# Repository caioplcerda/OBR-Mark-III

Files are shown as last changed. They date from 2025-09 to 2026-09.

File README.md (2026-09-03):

# OBR Mark III — Autonomous Rescue Robot

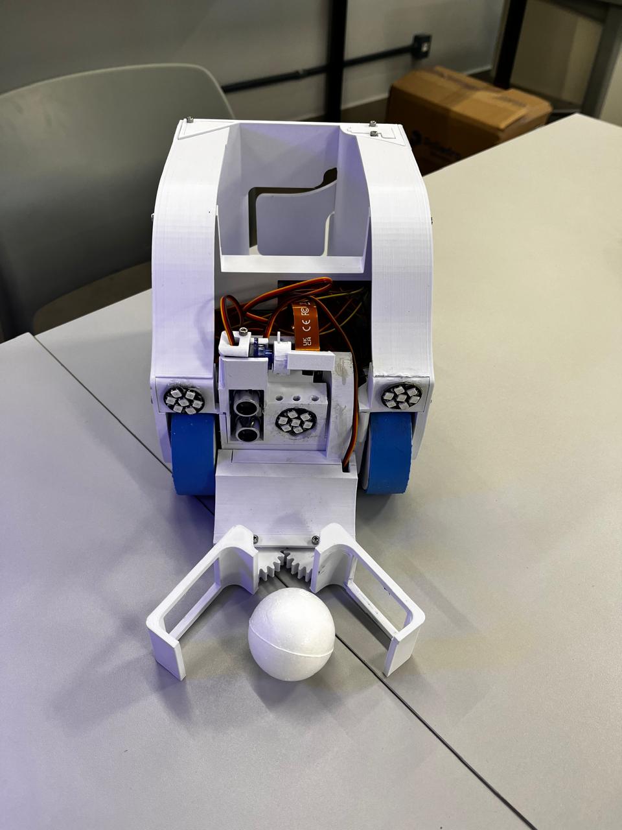
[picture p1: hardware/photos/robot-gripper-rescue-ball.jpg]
OBR Mark III closing its gripper on a rescue ball


An autonomous robot built for the **Olimpíada Brasileira de Robótica (OBR) 2025**, Brazil's
national robotics olympiad. It reads green intersection markers, avoids obstacles, collects
rescue balls with a rack-and-pinion gripper, and is tuned live from a browser while it drives.

**It follows the line with computer vision — no infrared sensor array.** Most line-following
robots read the track with a row of IR reflectance sensors a few millimetres above the
ground. This one has a camera and a **Raspberry Pi 5 (4 GB)**, and the line exists only as
pixels. Every steering decision comes out of a real-time OpenCV pipeline running at 480p.

Every structural part was designed in Fusion 360 and 3D printed in PLA. The tyres are custom
silicone, cast in a printed two-part mould, because printed wheels would not hold the track.

---

## What it does

### Finding the line in pixels

The pipeline never thresholds the whole frame looking for a blob. It samples it:

1. **Zero scan.** A horizontal scanline is taken close to the robot and the intensity
   profile along it is differentiated. The line's edges appear as derivative peaks, which
   is robust to uneven lighting in a way that a fixed brightness threshold is not. A
   minimum width of 12 px rejects noise and shadow edges.
2. **Circular scans.** From that first point, the algorithm sweeps arcs of radius 22 px
   through 180° to find where the line continues, then repeats from the new point —
   walking the track forward, several steps ahead of the robot. The traced path is kept in
   a rolling 7-point history.
3. **Steering.** A PID controller acts on the lateral offset of the nearest point, with the
   angle of the traced path fed forward. Because the path is known several points ahead,
   the robot slows into corners rather than discovering them late.

The scan-and-derivative approach is ported from a RoboCup Junior 2014 C++ reference
implementation (`rcj2014_port.py`) and re-derived in Python.

**Optical encoder feedback.** Each wheel reports its own speed, so the controller corrects
for the two motors never being quite identical — the usual reason a differential-drive robot
drifts on a straight line.

**Green intersection markers.** OBR arenas mark junctions with green patches indicating which
branch to take. The vision pipeline segments them in HSV, decides the turn, and executes a
180° reversal when two markers appear at once.

**Rescue-ball retrieval.** A rack-and-pinion gripper driven by an MG996R closes on the ball
and lifts it into an onboard reservoir.

**Camera mounted upside down.** The physical layout forced a 180° camera rotation; the
software rotates every frame before processing rather than fighting it mechanically.

**Thick-line support.** Morphological operations and contour analysis handle track lines up
to 20 mm wide, which break naive centroid-following.

**Live tuning over the network.** A Flask + Socket.IO server streams the robot's own camera
view to a browser and exposes PID gains, HSV thresholds and speed limits as live controls.
Tuning happens while the robot drives, with no reflashing and no reboot.

---

## The parts that were actually hard

### The Raspberry Pi 5 broke every GPIO library

The Pi 5 moved its GPIO behind the RP1 southbridge, and `RPi.GPIO` — the library every
Raspberry Pi robotics tutorial is written against — does not work on it. Nothing we started
from ran.

`hardware_control.py` therefore carries its own **GPIO backend abstraction**: a
`_GPIOBackendBase` interface with pin setup, PWM, and edge-triggered interrupts, implemented
over `lgpio`. Motor control, encoder interrupts and servo PWM all go through it, so the
control code is written once against an interface rather than against whichever library
happens to work on that board revision.

### The LEDs and the motors fought over the same timer

WS2812 addressable LEDs are timing-critical — each bit is a pulse width measured in hundreds
of nanoseconds, and they are usually driven from the Pi's PWM/DMA hardware. The motors need
PWM too. Driving the motors with *software* PWM produced jitter that corrupted the LED
signal; driving the LEDs while software PWM ran produced motor stutter.

The fix is one line of intent in the source — the backend forces **hardware PWM through
lgpio** specifically so the motor channels do not contend with the WS2812 timing. Finding
that took considerably longer than fixing it.

### Cascaded control, not a single PID

There are **three** PID controllers running at 50 Hz:

| Loop | Gains | Job |
|---|---|---|
| Directional (outer) | kp 0.9, kd 0.14 | Turns line error into a steering command |
| Left wheel velocity (inner) | kp 0.25, ki 0.35 | Holds the commanded wheel speed |
| Right wheel velocity (inner) | kp 0.25, ki 0.35 | Same, independently |

The outer loop asks for a turn rate; the inner loops make each wheel actually deliver its
share of it, from optical encoder feedback at 36 ticks per revolution. Without the inner
loops the robot steers correctly and still drifts, because no two DC motors respond
identically to the same duty cycle — the outer loop cannot tell the difference between "the
line moved" and "the left motor is lazy today."

If the encoders fail, the controller detects it and degrades to open loop rather than
stopping.

### Telling a junction apart from a sharp corner

The hardest perception problem in OBR is not finding the line. It is deciding whether the
line suddenly getting wider means *a junction is coming* or *the track turns 90° here* —
because the correct responses are opposite, and getting it wrong ends the run.

`_detect_intersection()` separates them geometrically. It samples the line's width across
the bottom strips and the lateral shift between the bottom and top centroids, then combines
them with the fitted path angle: wide and straight reads as an intersection; a large
centroid shift with a steep angle reads as a 90° curve.

### Nothing is trusted on one frame

Every detector — intersections, 90° curves, green markers — is **debounced over consecutive
frames** before the robot acts on it. A single frame of glare on the track, or one shadow
across a green patch, would otherwise send the robot down the wrong branch at full speed.

Thresholding is adaptive (`ADAPTIVE_THRESH_MEAN_C`, 21 px window) rather than fixed, because
competition lighting varies across the arena and a global threshold that works at one end of
the table fails at the other.

---

## The robot

| | |
|---|---|
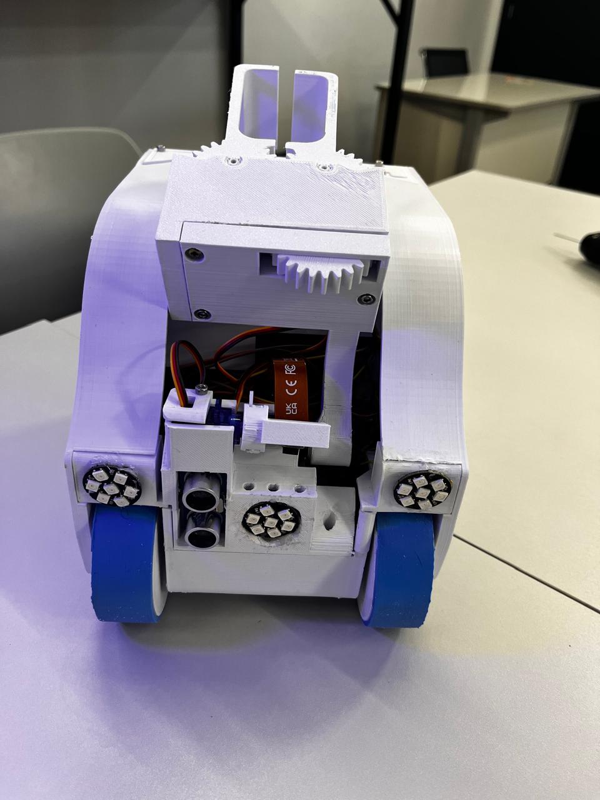
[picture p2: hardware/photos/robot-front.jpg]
Front
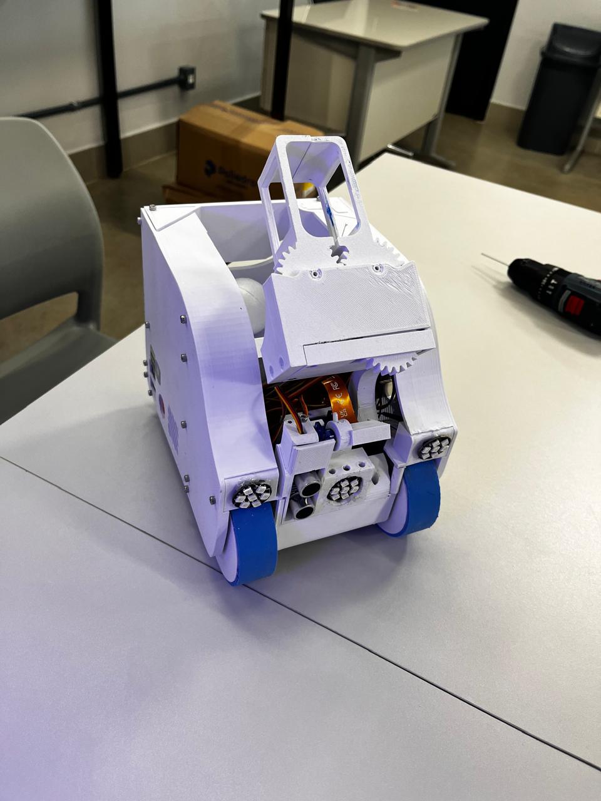
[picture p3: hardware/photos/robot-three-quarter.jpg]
Three-quarter
|  |  |
| Front — WS2812 indicator rings, ultrasonic sensor, silicone tyres | Reservoir loaded, gripper raised |

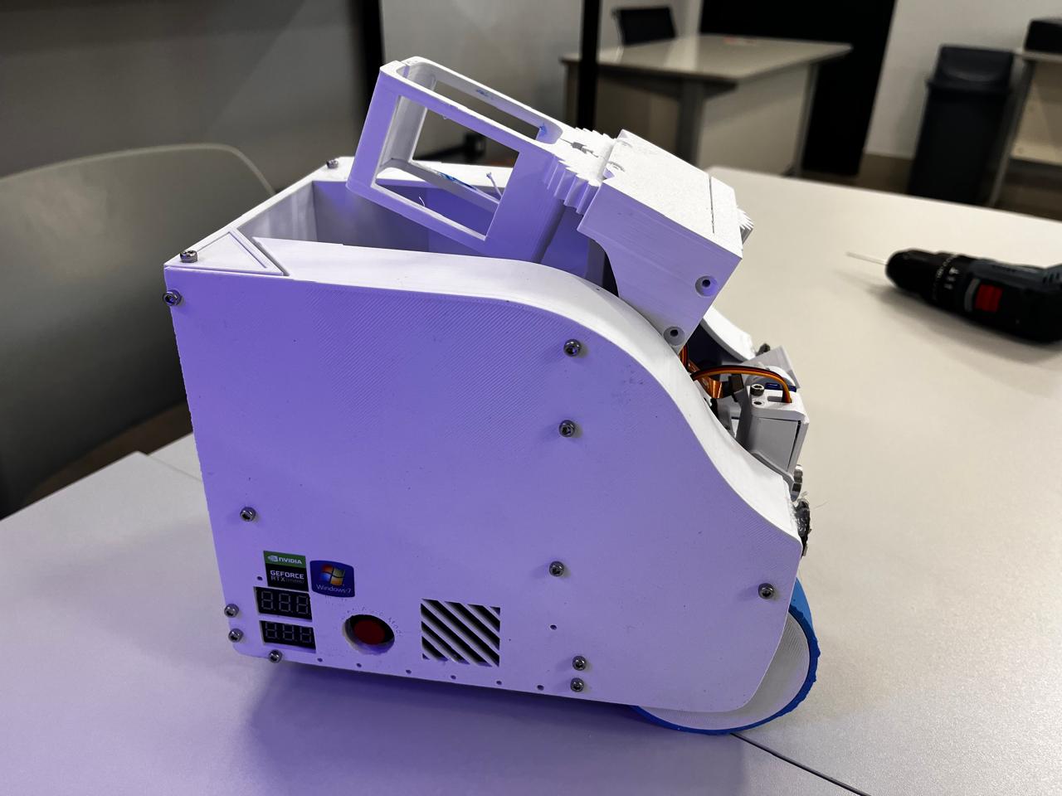
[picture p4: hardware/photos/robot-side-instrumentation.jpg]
Side view with voltmeters and power switch


Four panel voltmeters report pack and rail voltages at a glance, next to the main power
switch and a printed ventilation grille — useful when you are debugging in a pit between
rounds and need to know the battery state without a laptop.

---

## Architecture

```
src/
├── main.py               State machine — orchestrates behaviour and mode transitions
├── vision.py             Camera pipeline: rotation, thresholding, line and marker detection
├── line_follower.py      PID control, adaptive look-ahead, error computation
├── hardware_control.py   Motor, encoder and servo abstraction over the TB6612FNG drivers
├── web_stream.py         Flask + Socket.IO live video and remote calibration
├── led_control.py        WS2812 status indicators
├── rcj2014_port.py       Scan and error logic ported from the RoboCup Junior 2014 C++ reference
└── index.html            Calibration interface
```

Roughly 1,200 lines of Python across the core modules.

---

## Bill of materials

### Compute and sensing
| Part | Qty |
|---|---|
| Raspberry Pi 5, 4 GB — runs the whole vision pipeline on-board | 1 |
| Picamera3 Wide (mounted inverted) | 1 |
| Ultrasonic distance sensor | 1 |
| Optical encoder speed-sensor modules | 2 |

### Drive
| Part | Qty |
|---|---|
| DC motor, metal reduction gearbox, reversible | 2 |
| TB6612FNG dual H-bridge driver | 2 |
| Hex hub, 12 mm, for 8 mm shaft | 2 |
| Metal caster ball | 1 |
| Silicone tyres, cast in a printed mould | 2 |

### Actuators
| Part | Qty |
|---|---|
| TowerPro MG996R metal-gear servo (gripper) | 1 |
| SG90 9 g micro servo | 3 |
| Circular servo flange | 3 |

### Power
| Part | Qty |
|---|---|
| 18650 Li-Ion cell, 3.7 V (2550 mAh / Samsung 30Q 3000 mAh) | 8 |
| 4-cell 18650 holder, SMT PCB | 2 |
| BMS protection board, 5S 25 A 21 V | 1 |
| BMS protection board, 3S | 1 |
| MP1584 mini DC-DC step-down, 3 A | 5 |
| Mini-560 DC-DC step-down, 5 V | 1 |
| Adjustable current/voltage regulator | 2 |
| 3-digit digital voltmeter | 4 |
| 6A8 rectifier diode, 6 A 800 V | 2 |
| 1000 µF 16 V electrolytic capacitor | 1 |
| 100 pF 50 V ceramic capacitor | 10 |
| R13-507 16 mm momentary switch, 6 A | 1 |
| Dual 18650 charger | 1 |

### Indication and thermal
| Part | Qty |
|---|---|
| WS2812 addressable RGB module, 4-bit | 2 |
| WS2812 addressable RGB module, 7-bit | 1 |
| 40 × 40 × 10 mm fan | 2 |
| Self-adhesive heatsink | 5 |

### Mechanical
| Part | Qty |
|---|---|
| PLA filament — full chassis, gripper, mounts, wheel mould | — |
| M3 × 25 mm Philips screw | 50 |
| M3 nut | 30 |
| M2.5 × 6 mm Philips screw | 50 |
| M3 × 5 × 4.2 heat-set threaded insert | 1 kit |
| 6-way locking connector | 2 |

Threaded brass inserts were heat-set into the printed parts rather than tapping screws
directly into PLA, so the assembly survives repeated disassembly between competition rounds.

---

## CAD

**[`hardware/cad/obr-mark-iii.stl`](hardware/cad/obr-mark-iii.stl) — click to open it in
GitHub's interactive 3D viewer.** Rotate and zoom the assembly in the browser; nothing to
install.

Also committed: `obr-mark-iii.3mf`, print-ready with units and metadata preserved.
67,842 triangles.

### On the tyres

Printed PLA wheels slip on the OBR track surface, especially on inclines. Rather than buy
rubber wheels that would not fit the chassis geometry, we modelled a two-part mould, printed
it, and cast the tyres in silicone. The result grips the track and can be recast in minutes
if one tears mid-competition.

---

## Running it

The modules import each other flatly, and `web_stream.py` serves `index.html` from its own
directory, so run from inside `src/`:

```bash
pip install -r requirements.txt
cd src
python main.py
```

The calibration interface is then at `http://<robot-ip>:5000`.

Hardware-dependent imports (`RPi.GPIO`, `picamera2`, `libcamera`) are guarded, so the vision
and control modules can be exercised on a development machine without the robot attached.

---

## Tests

```bash
pip install -r requirements-dev.txt
pytest -q
```

31 tests over the two modules that decide where the robot goes: the scanline and
derivative line detection in `rcj2014_port.py`, and green-marker detection in `vision.py`.

The cases that matter are the negative ones. A dark speck narrower than the minimum line width
is noise, not the line. A green marker in the top half of the frame is track the robot has not
reached yet. A marker inside the outer 10% of the frame belongs to an adjacent lane. Each of
those filters exists because acting on the wrong one sends the robot down the wrong branch.

Writing them turned up a real bug: `calibrate_by_click` sliced the frame as
`frame_bgr[y, x:x+1]`, which produces a `(1, 3)` array. `cv2.cvtColor` needs `(1, 1, 3)` and
raised every time, and because the exception was caught and logged, click-to-calibrate had
never worked — it just looked like error handling.

## Repository layout

| Path | |
|---|---|
| `src/` | Robot code — the modules above |
| `tests/` | 31 tests over line detection and green-marker detection |
| `hardware/cad/` | Fusion 360 exports: STL and 3MF |
| `hardware/photos/` | Robot photographs |
| `experiments/` | Bring-up scripts kept from development: servo sweeps, LED and SPI tests, encoder checks, earlier vision attempts |
| `docs/` | Wiring and tuning notes |

`experiments/` is deliberately preserved. Getting three servos, an SPI LED strip and two
encoders working reliably took a lot of small scripts, and that iteration is part of the
project.

---

## Built by

Caio Lacerda — [github.com/caioplcerda](https://github.com/caioplcerda) ·
[linkedin.com/in/caio-lacerda](https://linkedin.com/in/caio-lacerda-61b7081b9)

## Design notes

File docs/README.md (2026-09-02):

# Notes

Wiring diagrams, pin assignments and PID tuning notes go here.

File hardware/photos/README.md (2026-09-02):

# Photos

| File | |
|---|---|
| `robot-gripper-rescue-ball.jpg` | Gripper closing on a rescue ball — README hero |
| `robot-front.jpg` | Front: WS2812 rings, ultrasonic sensor, silicone tyres |
| `robot-three-quarter.jpg` | Reservoir loaded, gripper raised |
| `robot-side-instrumentation.jpg` | Panel voltmeters, power switch, ventilation grille |

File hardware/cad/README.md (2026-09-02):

# CAD — OBR Mark III

Designed in Fusion 360, printed in PLA.

| File | | |
|---|---|---|
| `obr-mark-iii.stl` | 3.2 MB · 67,842 triangles | **GitHub renders this in an interactive 3D viewer — click it** |
| `obr-mark-iii.3mf` | 910 KB | Print-ready, keeps units and metadata |

Model bounding box: 272 × 363 × 190 mm.

The Fusion native `.f3d` (75 MB) is deliberately not committed — it is too large to be
useful in a git history and unreadable without Fusion. Ask if you want the source file,
or use the public share link in the main README.

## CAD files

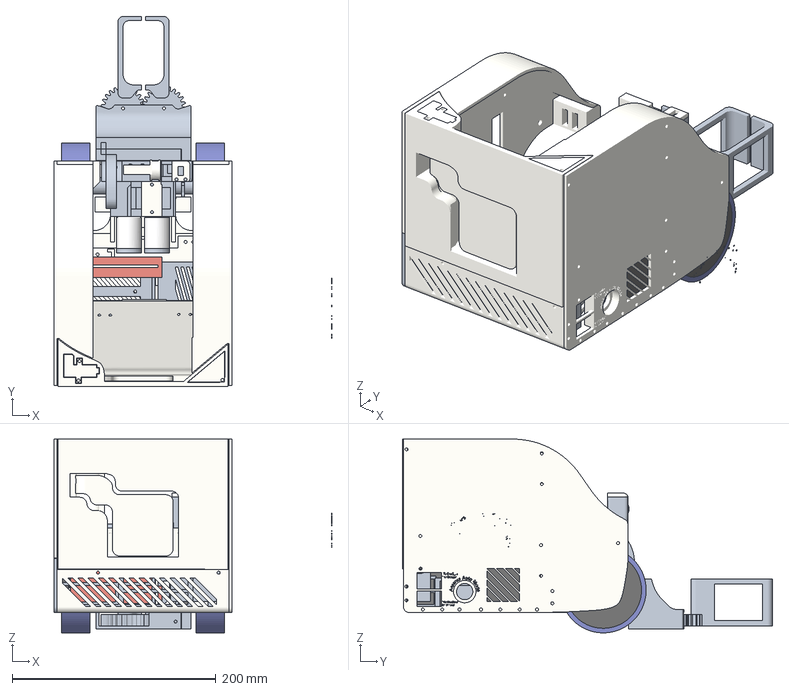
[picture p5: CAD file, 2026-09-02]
hardware/cad/obr-mark-iii.3mf
272.3 x 362.8 x 190.0 mm
ImageToStl.com_Captura+de+tela+2025-08-05+210000 (1)
ImageToStl.com_Captura+de+tela+2025-08-05+210000 (10)
ImageToStl.com_Captura+de+tela+2025-08-05+210000 (11)
ImageToStl.com_Captura+de+tela+2025-08-05+210000 (12)
ImageToStl.com_Captura+de+tela+2025-08-05+210000 (13)
ImageToStl.com_Captura+de+tela+2025-08-05+210000 (14)
ImageToStl.com_Captura+de+tela+2025-08-05+210000 (15)
ImageToStl.com_Captura+de+tela+2025-08-05+210000 (16)
ImageToStl.com_Captura+de+tela+2025-08-05+210000 (17)
ImageToStl.com_Captura+de+tela+2025-08-05+210000 (18)
ImageToStl.com_Captura+de+tela+2025-08-05+210000 (19)
ImageToStl.com_Captura+de+tela+2025-08-05+210000 (2)
ImageToStl.com_Captura+de+tela+2025-08-05+210000 (20)
ImageToStl.com_Captura+de+tela+2025-08-05+210000 (21)
ImageToStl.com_Captura+de+tela+2025-08-05+210000 (22)
ImageToStl.com_Captura+de+tela+2025-08-05+210000 (23)
ImageToStl.com_Captura+de+tela+2025-08-05+210000 (24)
ImageToStl.com_Captura+de+tela+2025-08-05+210000 (25)
ImageToStl.com_Captura+de+tela+2025-08-05+210000 (26)
ImageToStl.com_Captura+de+tela+2025-08-05+210000 (27)
ImageToStl.com_Captura+de+tela+2025-08-05+210000 (28)
ImageToStl.com_Captura+de+tela+2025-08-05+210000 (29)
ImageToStl.com_Captura+de+tela+2025-08-05+210000 (3)
ImageToStl.com_Captura+de+tela+2025-08-05+210000 (30)
ImageToStl.com_Captura+de+tela+2025-08-05+210000 (31)
ImageToStl.com_Captura+de+tela+2025-08-05+210000 (4)
ImageToStl.com_Captura+de+tela+2025-08-05+210000 (5)
ImageToStl.com_Captura+de+tela+2025-08-05+210000 (6)
ImageToStl.com_Captura+de+tela+2025-08-05+210000 (7)
ImageToStl.com_Captura+de+tela+2025-08-05+210000 (8)
ImageToStl.com_Captura+de+tela+2025-08-05+210000 (9)
Parede Esquerda (1)
Parede direita
Peneu AZUL (1)
Peneu AZUL
Porta bateria
Roda AZUL (1)
Roda AZUL
Segundo andar
Tampa
acoplador (1)
acoplador
base garra
camera
chassi (3) (1)
chassi (3)
chave bat
disco de encoder
engrenagem servo garra (1) (1)
engrenagem servo garra (1)
fecha garra
m
motor (1) (1)
motor (1)
rasp
rolamento (2) (1)
rolamento (2)
tampa caixa (1) (2)
tampa caixa
tampa motor (2)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

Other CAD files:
hardware/cad/obr-mark-iii.stl

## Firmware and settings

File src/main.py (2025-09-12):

# main.py corrigido
# Segue-linha robusto + UI web + botão físico.
# Ajustes:
#  - Logs claros para detecção de verde
#  - Tempos de curva fáceis de calibrar
#  - Giro menos brusco (bias reduzido)

import os
import cv2
import time
import json
import threading
import numpy as np
import math
from datetime import datetime
from collections import deque

USE_LEDS = True

WEB_AVAILABLE = True
SHARED_STATE = {
    "config": {},
    "last_frame": None,
    "speeds": {"left": 0, "right": 0},
    "view_mode": "preview",
    "status": "idle",
    "fps": 0.0,
    "log": [],
}
try:
    import web_stream
    if hasattr(web_stream, "SHARED_STATE"):
        SHARED_STATE = web_stream.SHARED_STATE
    WEB_AVAILABLE = True
except Exception:
    WEB_AVAILABLE = False

GPIO_AVAILABLE = True
try:
    import RPi.GPIO as GPIO
    GPIO.setwarnings(False)
    GPIO.setmode(GPIO.BCM)
    try:
        GPIO.setup(21, GPIO.IN, pull_up_down=GPIO.PUD_UP)
        GPIO.cleanup(21)
    except Exception:
        GPIO_AVAILABLE = False
except Exception:
    GPIO_AVAILABLE = False

from hardware_control import HardwareControl
from vision import Vision
try:
    from led_control import LedController
except Exception:
    LedController = None

PICAMERA_AVAILABLE = True
try:
    from picamera2 import Picamera2
    try:
        from libcamera import Transform
    except Exception:
        Transform = None
    PICAMERA_AVAILABLE = True
except Exception:
    PICAMERA_AVAILABLE = False

def log(msg: str):
    stamp = datetime.now().strftime("%H:%M:%S")
    line = f"[{stamp}] {msg}"
    print(line, flush=True)
    try:
        SHARED_STATE["log"].append(line)
        if len(SHARED_STATE["log"]) > 300:
            SHARED_STATE["log"] = SHARED_STATE["log"][-300:]
    except Exception:
        pass

class Camera:
    def __init__(self, width=640, height=480, rotate_180=False):
        self.width = width
        self.height = height
        self.rotate_180 = rotate_180
        self.picam = None
        self.cap = None
        try:
            import cv2 as _cv2
            _cv2.setNumThreads(1)
        except Exception:
            pass

        if PICAMERA_AVAILABLE:
            try:
                self.picam = Picamera2()
                if Transform is not None:
                    cfg = self.picam.create_video_configuration(
                        main={"size": (self.width, self.height), "format": "RGB888"},
                        transform=Transform(hflip=0, vflip=0),
                        buffer_count=3
                    )
                else:
                    cfg = self.picam.create_video_configuration(
                        main={"size": (self.width, self.height), "format": "RGB888"},
                        buffer_count=3
                    )
                self.picam.configure(cfg)
                try:
                    self.picam.set_controls({"FrameDurationLimits": (10000, 33333)})
                except Exception:
                    pass
                self.picam.start()
                log("Picamera2 iniciada em modo vídeo.")
            except Exception as e:
                log(f"Falha Picamera2: {e}. Usando OpenCV/USB.")
                self.picam = None

        if self.picam is None:
            self.cap = cv2.VideoCapture(0)
            self.cap.set(cv2.CAP_PROP_FRAME_WIDTH, self.width)
            self.cap.set(cv2.CAP_PROP_FRAME_HEIGHT, self.height)
            self.cap.set(cv2.CAP_PROP_FPS, 30)
            if not self.cap.isOpened():
                raise RuntimeError("Nenhuma câmera disponível.")

    def read(self):
        if self.picam is not None:
            rgb = self.picam.capture_array()
            frame_bgr = cv2.cvtColor(rgb, cv2.COLOR_RGB2BGR)
        else:
            ok, frame_bgr = self.cap.read()
            if not ok:
                raise RuntimeError("Falha ao ler frame da câmera USB.")
        if self.rotate_180:
            frame_bgr = cv2.rotate(frame_bgr, cv2.ROTATE_180)
        return frame_bgr

    def release(self):
        try:
            if self.picam is not None:
                self.picam.stop()
            if self.cap is not None:
                self.cap.release()
        except Exception:
            pass

class Robot:
    WIDTH = 640
    HEIGHT = 480

    BASE_SPEED = 50
    MIX_ANGLE = 0.7
    MAX_ANGLE = 50.0

    N_STRIPS = 5
    STRIP_H = 28
    STRIP_BOTTOM = 440

    INTERSECT_DEBOUNCE = 6
    C90_DEBOUNCE = 5
    GREEN_DEBOUNCE = 4

    # tempos calibráveis
    INTERSECT_FWD_TIME = 0.8
    TURN90_FWD_TIME = 0.3
    TURN90_TURN_TIME = 0.8 

    PID_DEFAULTS = {"kp": 0.5, "ki": 0.0, "kd": 0.12, "sample_time": 0.025}

    def __init__(self):
        self.running = False
        self.thread = None

        self.camera = Camera(self.WIDTH, self.HEIGHT, rotate_180=False)
        self.vision = Vision({}, log)
        self.hardware = HardwareControl({"pid": dict(self.PID_DEFAULTS)})

        self.history = deque(maxlen=5)
        self._intersect_seen = 0
        self._c90_seen = 0
        self._green_seen = 0
        self._green_last = None

    def start(self):
        if self.running:
            log("Robô já está rodando.")
            return
        self.running = True
        self.thread = threading.Thread(target=self._loop, daemon=True)
        self.thread.start()
        SHARED_STATE["status"] = "running"
        log("Loop principal iniciado.")

    def stop(self):
        self.running = False
        SHARED_STATE["status"] = "stopped"
        try: self.hardware.stop()
        except Exception: pass
        log("Parado.")

    def _drive(self, base_speed: float, error: float):
        try:
            self.hardware.set_motor_speed(base_speed, error)
        except Exception:
            pass

    def _forward_time(self, duration_s: float):
        self.hardware.set_motor_speed(self.BASE_SPEED, 0)
        start_time = time.time()
        while self.running and time.time() - start_time < duration_s:
            time.sleep(0.01)
        self.hardware.stop()

    def _turn_in_place_time(self, direction: str, duration_s: float):
        bias = 100 if direction == "left" else -100  # menos agressivo
        start_time = time.time()
        while self.running and time.time() - start_time < duration_s:
            self.hardware.set_motor_speed(0, bias)
            time.sleep(0.01)
        self.hardware.stop()

    def _loop(self):
        try:
            while self.running:
                frame = self.camera.read()
                bw = self._binarize(frame)

                cents, widths = [], []
                for i in range(self.N_STRIPS):
                    y0 = self.STRIP_BOTTOM - i*self.STRIP_H
                    c, w = self._strip_centroid(bw, y0, self.STRIP_H)
                    cents.append(c)
                    widths.append(w)

                valids = [p for p in cents if p is not None]
                angle = self._fit_angle(valids)

                is_intersection, is_curve90, _ = self._detect_intersection(bw, widths, cents, angle)

                if is_curve90:
                    self._c90_seen += 1
                else:
                    self._c90_seen = 0
                confirmed_curve90 = self._c90_seen >= self.C90_DEBOUNCE

                if is_intersection:
                    self._intersect_seen += 1
                else:
                    self._intersect_seen = 0
                confirmed_intersection = self._intersect_seen >= self.INTERSECT_DEBOUNCE

                green_centroids, green_dir = self.vision.detect_greens(frame)
                if green_dir:
                    self._green_last = green_dir
                    self._green_seen += 1
                else:
                    self._green_seen = 0
                confirmed_green = self._green_last if self._green_seen >= self.GREEN_DEBOUNCE else None

                # logs
                if confirmed_green:
                    log(f"Marcador verde confirmado: {confirmed_green}")

                if confirmed_intersection and not confirmed_curve90:
                    if confirmed_green == "uturn":
                        self._forward_time(self.INTERSECT_FWD_TIME)
                        self._turn_in_place_time("left", self.TURN90_TURN_TIME * 2)
                        log("Execução: U-Turn à esquerda")
                        self._green_seen = 0; self._intersect_seen = 0; self._green_last = None
                        continue
                    elif confirmed_green in ("left", "right"):
                        self._forward_time(self.TURN90_FWD_TIME)
                        self._turn_in_place_time(confirmed_green, self.TURN90_TURN_TIME)
                        log(f"Execução: curva {confirmed_green}")
                        self._green_seen = 0; self._intersect_seen = 0; self._green_last = None
                        continue
                    else:
                        self._forward_time(self.INTERSECT_FWD_TIME)
                        log("Execução: interseção sem verde → reto")
                        self._intersect_seen = 0
                        continue

                if valids:
                    offset = valids[0][0] - (self.WIDTH // 2)
                    error = float(offset) + self.MIX_ANGLE * float(angle)
                    self._drive(self.BASE_SPEED, error)
                else:
                    self.hardware.stop()

                SHARED_STATE["last_frame"] = frame
                SHARED_STATE["speeds"] = {
                    "left": self.hardware.last_left_speed,
                    "right": self.hardware.last_right_speed
                }
                time.sleep(0.01)
        except Exception as e:
            log(f"Erro no loop principal: {e}")
        finally:
            try: self.hardware.stop()
            except Exception: pass

    # ==== visão utilitários ====
    def _binarize(self, frame_bgr):
        gray = cv2.cvtColor(frame_bgr, cv2.COLOR_BGR2GRAY)
        bw = cv2.adaptiveThreshold(gray, 255, cv2.ADAPTIVE_THRESH_MEAN_C,
                                   cv2.THRESH_BINARY_INV, 21, 7)
        return bw

    def _strip_centroid(self, bw, y0, h):
        H, W = bw.shape[:2]
        y0 = max(0, min(H - 1, int(y0)))
        y1 = max(0, min(H, int(y0 + h)))
        roi = bw[y0:y1, :]
        colsum = roi.sum(axis=0)
        if colsum.max() < 255 * h * 0.05:
            return None, 0
        x = np.arange(0, W, dtype=np.float32)
        cx = float((x * colsum).sum() / (colsum.sum() + 1e-6))
        cy = int((y0 + y1) / 2)
        return (int(cx), int(cy)), int(np.count_nonzero(colsum))

    def _fit_angle(self, pts):
        if len(pts) < 2:
            return 0.0
        xs = np.array([p[0] for p in pts], dtype=np.float32)
        ys = np.array([p[1] for p in pts], dtype=np.float32)
        A = np.vstack([ys, np.ones_like(ys)]).T
        alpha, _ = np.linalg.lstsq(A, xs, rcond=None)[0]
        angle_deg = np.degrees(np.arctan2(alpha, 1.0))
        return float(np.clip(angle_deg, -self.MAX_ANGLE, self.MAX_ANGLE))

    def _detect_intersection(self, bw, widths, cents, angle_deg):
        bottom_widths = [w for w in widths[:3] if w > 0]
        is_wide = len(bottom_widths) > 0 and np.mean(bottom_widths) > 300
        is_intersection = is_wide and abs(angle_deg) < 15

        num_valid_cents = sum(1 for c in cents if c is not None)
        is_curve90 = False
        if num_valid_cents >= 3:
            bottom_cx = cents[0][0] if cents[0] is not None else self.WIDTH // 2
            top_cx = cents[-1][0] if cents[-1] is not None else self.WIDTH // 2
            shift_px = abs(bottom_cx - top_cx)
            is_curve90 = (shift_px > 80) and (abs(angle_deg) > 20)
        elif num_valid_cents >= 2:
            is_curve90 = abs(angle_deg) > 25

        return is_intersection, is_curve90, False

def _wire_web(robot: Robot):
    if not WEB_AVAILABLE:
        return
    try:
        if hasattr(web_stream, "register_robot"):
            web_stream.register_robot(robot)
            log("Robô registrado no servidor web.")
    except Exception as e:
        log(f"Falha ao integrar com web_stream: {e}")

def _setup_button(robot: Robot):
    if not GPIO_AVAILABLE:
        log("GPIO indisponível: sem botão físico.")
        return
    for pin in [21, 4]:
        try:
            GPIO.setup(pin, GPIO.IN, pull_up_down=GPIO.PUD_UP)
            def _toggle(channel):
                if GPIO.input(pin) == GPIO.LOW:
                    if robot.running:
                        robot.stop()
                    else:
                        robot.start()
            GPIO.add_event_detect(pin, GPIO.FALLING, callback=_toggle, bouncetime=300)
            log(f"Botão físico pronto no BCM {pin}.")
            break
        except Exception as e:
            log(f"Falha botão BCM {pin}: {e}")

def main():
    robot = Robot()
    _wire_web(robot)
    _setup_button(robot)

    if WEB_AVAILABLE and hasattr(web_stream, "app"):
        host = os.environ.get("HOST", "0.0.0.0")
        port = int(os.environ.get("PORT", "5000"))
        try:
            if hasattr(web_stream, "socketio"):
                web_stream.socketio.run(web_stream.app, host=host, port=port, allow_unsafe_werkzeug=True)
            else:
                web_stream.app.run(host=host, port=port)
        finally:
            robot.stop()
    else:
        try:
            while True:
                time.sleep(1.0)
        except KeyboardInterrupt:
            robot.stop()

if __name__ == "__main__":
    main()

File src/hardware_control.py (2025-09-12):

# hardware_control.py
# Controle de motores TB6612FNG (canal B), com opção de encoders (TPR=36).
# Usa backend lgpio (PWM por hardware) para não travar com WS2812.
# Direita invertida (chassi espelhado), deadband alto para vencer inércia,
# e "snap reto" quando erro é pequeno.

import time
import threading

# ------------------ Backends GPIO (forçando lgpio) ------------------
class _PWMBase:
    def start(self, duty): raise NotImplementedError
    def ChangeDutyCycle(self, duty): raise NotImplementedError
    def stop(self): raise NotImplementedError

class _GPIOBackendBase:
    OUT = 1
    IN = 0
    PUD_UP = 2
    RISING = 31
    def setup(self, pin, mode, pull_up_down=None): raise NotImplementedError
    def output(self, pin, level): raise NotImplementedError
    def input(self, pin): raise NotImplementedError
    def PWM(self, pin, freq_hz): raise NotImplementedError
    def add_event_detect(self, pin, edge, callback): raise NotImplementedError
    def remove_event_detect(self, pin): pass
    def cleanup(self): pass

class _LGPIOBackend(_GPIOBackendBase):
    def __init__(self, chip_index=0):
        import lgpio
        self._lgpio = lgpio
        self._h = self._lgpio.gpiochip_open(chip_index)
        self.OUT = 1; self.IN = 0; self.PUD_UP = 2
        self.RISING = self._lgpio.RISING_EDGE
        self._alerts = {}
    def _claim_out(self, pin, init=0):
        self._lgpio.gpio_claim_output(self._h, pin, init)
    def _claim_in(self, pin, pud=None):
        flags = 0
        if pud == self.PUD_UP:
            flags |= self._lgpio.SET_PULL_UP
        self._lgpio.gpio_claim_input(self._h, pin, flags)
    def setup(self, pin, mode, pull_up_down=None):
        if mode == self.OUT: self._claim_out(pin, 0)
        else: self._claim_in(pin, pull_up_down)
    def output(self, pin, level):
        self._lgpio.gpio_write(self._h, pin, 1 if level else 0)
    def input(self, pin):
        return self._lgpio.gpio_read(self._h, pin)
    class _PWM(_PWMBase):
        def __init__(self, lgpio_mod, handle, pin, freq):
            self._lgpio = lgpio_mod; self._h = handle; self._pin = pin; self._freq = int(freq)
            self._lgpio.gpio_claim_output(self._h, pin, 0)
        def start(self, duty):
            self.ChangeDutyCycle(duty)
        def ChangeDutyCycle(self, duty):
            self._lgpio.tx_pwm(self._h, self._pin, self._freq, max(0.0, min(100.0, float(duty))))
        def stop(self):
            try: self._lgpio.tx_pwm(self._h, self._pin, self._freq, 0)
            except Exception: pass
    def PWM(self, pin, freq_hz):
        return self._PWM(self._lgpio, self._h, pin, freq_hz)
    def add_event_detect(self, pin, edge, callback):
        self._lgpio.gpio_claim_input(self._h, pin, self._lgpio.SET_PULL_UP)
        self._lgpio.gpio_claim_alert(self._h, pin, self.RISING, 0)
        def _cb(_chip, _gpio, level, _tick):
            try:
                if level == 1:
                    callback(pin)
            except Exception:
                pass
        self._alerts[pin] = _cb
        self._lgpio.set_alert_func(self._h, pin, _cb)
    def remove_event_detect(self, pin):
        if pin in self._alerts:
            try: self._lgpio.set_alert_func(self._h, pin, None)
            except Exception: pass
            self._alerts.pop(pin, None)
    def cleanup(self):
        try:
            for pin in list(self._alerts.keys()):
                self.remove_event_detect(pin)
        except Exception:
            pass
        try:
            self._lgpio.gpiochip_close(self._h)
        except Exception:
            pass

def _make_backend_forced_lgpio():
    return _LGPIOBackend(), "lgpio"

# ------------------ PID simples ------------------
class PIDController:
    def __init__(self, kp=0.4, ki=0.0, kd=0.1, setpoint=0.0, sample_time=0.01, out_min=None, out_max=None):
        self.kp=float(kp); self.ki=float(ki); self.kd=float(kd)
        self.setpoint=float(setpoint); self.sample_time=float(sample_time)
        self._prev_error=0.0; self._integral=0.0; self._last_t=time.time()
        self.out_min=out_min; self.out_max=out_max
    def reset(self):
        self._prev_error=0.0; self._integral=0.0; self._last_t=time.time()
    def calculate(self, measurement):
        now=time.time(); dt=now-self._last_t
        if dt<self.sample_time: return self._prev_error
        error=self.setpoint-float(measurement)
        self._integral = max(-200.0, min(200.0, self._integral + error*dt))
        derivative=(error-self._prev_error)/dt if dt>0 else 0.0
        out=(self.kp*error)+(self.ki*self._integral)+(self.kd*derivative)
        if self.out_min is not None: out=max(self.out_min,out)
        if self.out_max is not None: out=min(self.out_max,out)
        self._prev_error=error; self._last_t=now
        return out
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

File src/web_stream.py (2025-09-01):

# web_stream.py
# Flask + Socket.IO + MJPEG robusto.
# Inclui "FORCE_RGB_INPUT" para evitar cores trocadas e stream preto.

import cv2
from flask import Flask, Response, send_from_directory, jsonify
from flask_socketio import SocketIO, emit
import threading
import time

app = Flask(__name__)
socketio = SocketIO(app, async_mode="threading", cors_allowed_origins="*")

# Se a imagem sair com cores invertidas, deixe True
FORCE_RGB_INPUT = False

# Estado compartilhado; o main.py pode sobrescrever esse dict
SHARED_STATE = {
    "config": {},
    "last_frame": None,          # numpy array (BGR ou RGB com flag)
    "speeds": {"left": 0, "right": 0},
    "status": "idle",
    "view_mode": "preview",
    "fps": 0.0,
    "log": [],
}

_robot = None
_state_lock = threading.Lock()

def register_robot(robot):
    global _robot
    _robot = robot

def _get_frame():
    with _state_lock:
        return SHARED_STATE.get("last_frame", None)

# MJPEG
def mjpeg_generator():
    while True:
        frame = _get_frame()
        if frame is None:
            time.sleep(0.05)
            continue
        try:
            img = frame
            if FORCE_RGB_INPUT:
                # se pipeline estiver em RGB, converte para BGR antes de encodar
                img = cv2.cvtColor(img, cv2.COLOR_RGB2BGR)
            ok, jpg = cv2.imencode(".jpg", img)
            if not ok:
                time.sleep(0.01)
                continue
            data = jpg.tobytes()
            yield (b"--frame\r\n"
                   b"Content-Type: image/jpeg\r\n\r\n" + data + b"\r\n")
        except Exception:
            time.sleep(0.01)

# Rotas
@app.route("/")
def root():
    return send_from_directory(".", "index.html")

@app.route("/index.html")
def serve_index():
    return send_from_directory(".", "index.html")

@app.route("/stream")
def stream():
    return Response(mjpeg_generator(),
                    mimetype="multipart/x-mixed-replace; boundary=frame")

@app.route("/state")
def state():
    with _state_lock:
        return jsonify({
            "status": SHARED_STATE.get("status", ""),
            "speeds": SHARED_STATE.get("speeds", {}),
            "fps": SHARED_STATE.get("fps", 0),
            "view_mode": SHARED_STATE.get("view_mode", "preview"),
        })

# Socket.IO
@socketio.on("connect")
def on_connect():
    emit("log_message", {"text": "Socket conectado."})
    with _state_lock:
        emit("status", {
            "status": SHARED_STATE.get("status", "idle"),
            "speeds": SHARED_STATE.get("speeds", {"left": 0, "right": 0}),
            "fps": SHARED_STATE.get("fps", 0)
        })

@socketio.on("command")
def on_command(cmd):
    global _robot
    name = (cmd or {}).get("name", "")
    data = (cmd or {}).get("data", {}) or {}

    if _robot is None:
        emit("log_message", {"text": "Nenhum robô registrado ainda."})
        return

    try:
        if name == "start_robot":
            _robot.start()
            emit("log_message", {"text": "Robô iniciado."})
        elif name == "stop_robot":
            _robot.stop()
            emit("log_message", {"text": "Robô parado."})
        elif name == "set_view_mode":
            _robot.set_view_mode(data.get("mode", "preview"))
        elif name == "calibrate_pixel":
            x = int(data.get("x", 0))
            y = int(data.get("y", 0))
            color = data.get("color", "black")
            ok = _robot.calibrate_pixel(x, y, color)
            emit("log_message", {"text": f"Calibração ({color}) {x},{y} -> {ok}"})
        elif name == "save_config":
            ok = _robot.save_config(data)
            emit("log_message", {"text": f"Config salva: {ok}"})
        else:
            emit("log_message", {"text": f"Comando desconhecido: {name}"})
    except Exception as e:
        emit("log_message", {"text": f"Erro no comando {name}: {e}"})


if __name__ == "__main__":
    socketio.run(app, host="0.0.0.0", port=5000, allow_unsafe_werkzeug=True)

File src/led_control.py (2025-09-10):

# led_control.py
# Simple controller for a single strip of WS2812 (NeoPixel) LEDs.

try:
    from rpi_ws281x import PixelStrip, Color, ws
    RPI_WS281X_OK = True
except Exception:
    RPI_WS281X_OK = False

TOTAL_LEDS = 21

class LedController:
    def __init__(self, pin=12, brightness=128):
        """
        pin: GPIO for the DIN of the WS2812 LEDs (GPIO12 recommended).
        brightness: 0..255 (global brightness for the strip).
        """
        self.enabled = False
        self.strip = None

        if not RPI_WS281X_OK:
            print("[LED] rpi_ws281x library not available — LEDs disabled.")
            return

        try:
            self.strip = PixelStrip(
                num=TOTAL_LEDS,
                pin=pin,
                freq_hz=800000,
                dma=10,
                invert=False,
                brightness=brightness,
                channel=0,
                strip_type=ws.WS2811_STRIP_GRB
            )
            self.strip.begin()
            self.enabled = True
            print(f"[LED] LedController initialized for {TOTAL_LEDS} LEDs.")
        except Exception as e:
            print(f"[LED] Failed to initialize PixelStrip: {e}")
            self.enabled = False

    @staticmethod
    def _rgb(r, g, b):
        """Converts RGB tuple to Color object."""
        return Color(int(r), int(g), int(b))

    def set_all(self, r, g, b, show=True):
        """
        Sets all LEDs in the strip to the same color.
        """
        if not self.enabled:
            return

        color_obj = self._rgb(r, g, b)
        for i in range(self.strip.numPixels()):
            self.strip.setPixelColor(i, color_obj)

        if show:
            self.strip.show()

    def cleanup(self):
        """Turn off all LEDs on cleanup."""
        if not self.enabled:
            return
        self.set_all(0, 0, 0)

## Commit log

2025-07-28 Refatorando e aprimorando seu código do robô seguidor de linha para a OBR 2025.
2025-07-28 Adds web calibration interface and integration with new hardware.
2025-07-28 Estou implementando uma velocidade adaptativa baseada na curvatura da linha.
2025-07-29 Eu corrigi a regra de finalização para incluir uma parada de 5 segundos.
    [hardware_control.py, main.py, vision.py]
2025-07-29 Adiciona botão de início na interface web.
2025-07-29 Adiciona exibição de status detalhado no stream de vídeo.
2025-07-29 Corrigi a proporção e adicionei calibração interativa com visualização de máscara.
    [main.py, vision.py, web_stream.py]
2025-07-29 Eu corrigi o botão de início da web usando threading.Event.
    [main.py, web_stream.py]
2025-07-29 Eu corrigi a atualização do stream e o desenho da trajetória usando `threading.Lock`.
    [web_stream.py]
2025-07-29 Corrigi a exibição de status e velocidade no stream de vídeo.
    [web_stream.py]
2025-07-29 Adiciona console de logs na interface web.
2025-07-29 Corrigindo e fortalecendo a lógica de verificação do botão de início.
    [main.py]
2025-07-30 Refatorei a comunicação entre threads para usar um dicionário de estado global.
2025-07-30 Consertei a comunicação do front-end e a exibição de logs na web.
2025-07-30 Corrigi um ValueError causado por um desempacotamento incorreto de valores.
    [line_follower.py]
2025-07-30 Refatoração final para corrigir cores, calibração e comunicação web.
    [main.py, web_stream.py]
2025-07-30 Refactor frontend/backend communication using WebSockets.
    This commit addresses several issues with the robot control interface:
    - The inefficient HTTP polling for logs and commands has been replaced with a persistent WebSocket connection using Flask-SocketIO.
    - The frontend JavaScript is now robust, ensuring DOM elements are loaded before event listeners are attached, fixing the non-functional buttons.
    - Real-time log streaming from the backend to the frontend is now implemented.
    Additionally, two specific bugs have been fixed:
    - A color inversion issue causing a greenish video stream has been corrected by changing the color space conversion from RGBA2BGR to RGBA2RGB.
    - A minor bug in the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
    [main.py, vision.py, web_stream.py]
2025-07-30 Fix 500 Internal Server Error in the video stream.
    This commit fixes a crash in the `/stream` endpoint that was causing a 500 error and preventing the video from displaying.
    The root cause was a color space mismatch. The application was internally using an RGB frame, which caused issues with OpenCV's drawing and encoding functions that expect BGR.
    The fix involves:
    - Reverting `main.py` to produce BGR frames, which is the standard for OpenCV.
    - Moving the color space conversion to the last moment in `web_stream.py`. The final frame is converted from BGR to RGB right before being encoded into a JPEG. This ensures the browser receives the correct color format.
    - Adding a `try...except` block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
    [main.py, web_stream.py]
2025-07-30 Fix: Resolve 500 error and color issues in video stream
    This commit addresses two issues in the web video stream:
    1. A 500 Internal Server Error was occurring on the `/stream` route. This was caused by the `stream_route` function not returning a Flask `Response` object. The function now correctly returns a streaming response.
    2. The video stream had incorrect colors (swapped red and blue channels). This was due to an unnecessary color space conversion from BGR to RGB before JPEG encoding. The `cv2.imencode` function expects BGR format, so the conversion was removed.
    [web_stream.py]
2025-07-30 feat: Add calibration for white and silver colors
    This commit introduces a calibration feature for white and silver colors to improve detection accuracy and prevent the robot from incorrectly entering the rescue state.
    - The web UI dropdown now includes options for "Branco (Fundo)" and "Prata (Área de Resgate)".
    - The hardcoded HSV values for silver have been moved to the shared configuration, making them dynamic. A new entry for white has also been added.
    - The `calibrate_by_click` function in the vision module now handles 'white' and 'silver' arguments, allowing you to calibrate these colors by clicking on the video stream.
    - The color detection logic now uses these configurable values.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
    [vision.py, web_stream.py]
2025-07-30 feat: Implement advanced line following algorithm
    This commit replaces the simple centroid-based line follower with a more robust algorithm ported from the legacy `RCJ_2014.cpp` codebase.
    The new implementation includes:
    - **Advanced Line Detection:** A new `advanced_vision.py` module implements `scanline` and `scancircle` functions. It uses grayscale derivative analysis to accurately find the line's edges, making it less sensitive to lighting changes and line width variations.
    - **Predictive Path Following:** The main loop now uses a "snake" of scan points to predict the line's path, allowing for look-ahead control which improves cornering performance.
    - **Enhanced Visualization:** The web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
    [advanced_vision.py, main.py, web_stream.py]
2025-07-30 fix: Prevent crash during rescue mode activation
    This commit fixes a bug that caused a TypeError when the robot entered rescue mode.
    The `update_stream_data` function signature was modified in a previous commit, but the corresponding call in the `rescue.py` module was not updated. This caused a crash when the function was called with a missing number of arguments.
    The fix makes the parameters of `update_stream_data` optional and handles cases where they are not provided. This makes the function more robust and resolves the crash, allowing the silver calibration and rescue mode to function correctly.
    [main.py]
2025-07-30 fix: Handle calibration errors and prevent server crashes
    This commit includes two important bug fixes to improve stability and user experience.
    1. **Fix calibration IndexError:** The JavaScript in `index.html` was updated to correctly scale the mouse click coordinates. Previously, clicking on a resized video feed would send incorrect, out-of-bounds coordinates to the backend, causing an `IndexError`. The coordinates are now scaled relative to the video's original 640x480 resolution.
    2. **Prevent server crashes:** A `try...except Exception` block was added to the main `while` loop in `main.py`. This prevents any unhandled runtime error from crashing the main thread, which would also term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
    [main.py]
2025-08-28 Revert "Remove line detection thresholds"
    [advanced_vision.py, line_follower.py, main.py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]
2025-08-28 Add forward movement test script without encoders
2025-08-28 Prevent PWM destructor error on exit
2025-08-30 Use B-channel drivers and invert right motor
    [hardware_control.py]
2025-08-30 Rotate camera and adopt circular line scanning
2025-08-30 refactor: Translate C++ line follower to modular Python
    This commit replaces the previous line follower with a new implementation translated from the user-provided C++ code (`RJC_2014.cpp`).
    The new implementation is structured into three main modules for better modularity and maintainability:
    - `main.py`: The central orchestrator that runs the main control loop, initializes all components, and coordinates between vision, hardware, and the web stream.
    - `vision.py`: A new module containing the direct translation of the C++ image processing logic. It includes the unique `scanline` and `scancircle` algorithms for detecting the line and its angle.
    - `hardware_control.py`: The existing hardware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
    [advanced_vision.py, line_follower.py, main.py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]
2025-08-30 fix(vision): Correct TypeError in scancircle function
    The `cv2.ellipse2Poly` function requires its angle arguments (`arcStart`, `arcEnd`) to be integers. The previous code was passing floating-point values due to the use of float division (`/`), which caused a `TypeError` at runtime.
    This commit fixes the bug by explicitly casting the `angle_start` and `angle_end` variables to integers before they are passed to the `cv2.ellipse2Poly` function. A comment has also been added to clarify why the type cast is necessary.
    [vision.py]
2025-08-30 Revert "fix(vision): Correct TypeError in scancircle function"
    [vision.py]
2025-08-30 Revert "Revert "fix(vision): Correct TypeError in scancircle function""
    [vision.py]
2025-08-30 Revert "Revert "Revert "fix(vision): Correct TypeError in scancircle function"""
    [vision.py]
2025-08-30 Revert "refactor: Translate C++ line follower to modular Python"
    [advanced_vision.py, line_follower.py, main.py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]
2025-09-05 Restrict green detection to lower frame and handle intersection moves
2025-09-05 Use encoder ticks for intersection maneuvers and improve button setup
2025-09-08 Create Teste de servo
2025-09-08 Create servo
2025-09-09 feat: Create servo tester Flask application
    This commit introduces a new script, `servo_tester.py`, which runs a standalone Flask web server for testing and calibrating servo motors.
    The application provides a simple web interface with fields to input a GPIO number and a raw PWM value (500-2500). This allows for direct control of the servo's position, which is useful for finding the correct PWM values for specific angles.
    Key features:
    - Runs on port 5001 to avoid conflicts with the main application.
    - Uses the `pigpio` library for stable PWM signal generation.
    - Includes a shutdown button on the UI to turn off all active servos.
    - Implements a cleanup routine using `atexit` to ensure serv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
2025-09-09 Create servotest
2025-09-09 Individualize servo positions and add C/D for one servo
    The servo configuration in `hardware_control.py` was updated to allow for individual A and B pulse width values for each of the four servos.
    Additionally, C and D positions were added for the first servo (GPIO 26).
    To support this, the `set_servo` method was updated:
    - Position validation now checks against the available positions for each specific servo.
    - A new `_servo_pos` state variable was introduced to track the last commanded position, allowing the smoothing feature to work correctly between any defined points (A, B, C, D, etc.).
    [hardware_control.py]
2025-09-09 Revert "teste servo sem motor andar"
    [hardware_control.py]
2025-09-09 Update servo 18 positions to include C
    As requested, the configuration for the servo on pin 18 has been updated to `{"A": 1444, "B": 2000, "C": 2388}`.
    This change redefines the servo's movement range and adds a third position, 'C'.
2025-09-10 Fix: Correct intersection turning logic to prevent spinning
    The robot was getting stuck in an infinite turning loop at intersections. This was caused by using the minimum encoder tick count (`min(get_ticks())`) to measure the duration of a turn.
    When turning, the inner wheel moves much less than the outer wheel, so its tick count increases slowly. Using the minimum count meant the turn completion target was often never reached, causing the robot to spin indefinitely.
    This commit changes the logic to use the maximum encoder tick count (`max(get_ticks())`). This measures the turn based on the outer wheel's travel, which is a more reliable and accurate way to control the turn duration. This e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
    [main.py]
2025-09-10 Fix: Reset PID controller on start to prevent spinning
    The robot would follow the line for a second and then start spinning uncontrollably. This was caused by the directional PID controller's integral (I) term accumulating error over time without being reset between runs.
    This commit fixes the issue by adding a call to `self.hardware.dir_pid.reset()` in the `Robot.start()` method. This ensures that the PID controller starts in a clean state for every run, preventing the integral term from accumulating and causing the robot to spin out.
    [main.py]
2025-09-10 Fix: Debounce C90 detection and improve stop button robustness
    This commit implements two improvements to the robot's logic based on user feedback.
    1. **Debounce C90 Detections:**
    The logic for detecting 90-degree curves (C90) was reacting to single, noisy frames. A debouncing mechanism has been added, similar to the one for intersections. The robot now only confirms a C90 curve if it is detected for `C90_DEBOUNCE` consecutive frames.
    2. **Improve Stop Button Robustness:**
    To make the stop button more responsive, especially during blocking movement commands, extra checks for the `self.running` flag have been added to the `_forward_ticks` and `_turn_in_place_ticks` loops. This ens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
    [main.py]
2025-09-10 Fix: Tune PID controller to reduce oscillations
    The robot was incorrectly detecting intersections and C90 curves on straight lines. This was caused by an overly aggressive PID controller, which led to oscillations in the robot's movement. These oscillations were then misinterpreted by the vision system as curves or wide lines.
    This commit tunes the PID controller by lowering the proportional (kp) and derivative (kd) gains in `PID_DEFAULTS`. This makes the robot's line-following behavior smoother and more stable, which should eliminate the false detections.
    - `kp` reduced from 0.9 to 0.6
    - `kd` reduced from 0.14 to 0.1
    [main.py]
2025-09-10 Feat: Set all 21 LEDs to static white
    This commit refactors the LED control system to set all 21 LEDs to a static white color at medium brightness.
    - The `LedController` class in `led_control.py` has been simplified. All complex, state-specific methods have been removed in favor of a single, general-purpose `set_all(r, g, b)` method. `TOTAL_LEDS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
    - `main.py` has been updated to call `self.leds.set_all(180, 180, 180)` upon robot initialization. All other calls to the now-defunct LED status methods have been removed to reflect this new, simpler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
2025-09-10 Feat: Synchronize LEDs with robot's running state
    This commit changes the LED behavior to be tied to the robot's operational state.
    - The `LedController` is initialized with the LEDs off by default.
    - When `Robot.start()` is called, the LEDs are turned on to a medium-white color.
    - When `Robot.stop()` is called, the LEDs are turned off.
    This provides clear visual feedback on whether the robot is active or idle.
2025-09-10 Revert "Feat: Synchronize LEDs with robot's running state"
    [main.py]
2026-09-02 Restructure as portfolio project
    - Move flight code into src/, bring-up scripts into experiments/
    - Add hardware/cad and hardware/photos for CAD exports and images
    - Rewrite README in English, leading with the control and vision work
    - Add .gitignore
2026-09-02 Add CAD: OBR Mark III STL and 3MF exports
    [obr-mark-iii.3mf, obr-mark-iii.stl]
2026-09-02 Add robot photos and full bill of materials
    - Four photographs: hero, front, three-quarter, instrumentation side
    - Complete BOM from build records: compute, drive, actuators, power,
    indication, thermal, mechanical
    - Document heat-set inserts and the silicone tyre casting
2026-09-03 Document the genuinely hard problems
    Pi 5 GPIO migration and the custom lgpio backend, the WS2812/motor PWM
    timing contention, cascaded PID architecture, junction vs 90-degree curve
    disambiguation, and per-detector debouncing. These were the difficult
    parts and the README did not mention them.
2026-09-03 test: cover line detection and green-marker detection
    31 tests over the two modules that decide where the robot goes:
    scanline/derivative line detection in rcj2014_port.py and green-marker
    detection in vision.py. The negative cases carry most of the weight — a
    speck narrower than the minimum line width, a marker in the top half of
    the frame, a marker inside the side margins — since acting on any of
    those sends the robot down the wrong branch.
    Fixes a bug the tests found: calibrate_by_click sliced the frame as
    frame_bgr[y, x:x+1], giving a (1, 3) array. cv2.cvtColor needs (1, 1, 3)
    and raised on every call. The exception was caught and logged, so
    click-to-calibrate had never worked and l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
    [vision.py]
